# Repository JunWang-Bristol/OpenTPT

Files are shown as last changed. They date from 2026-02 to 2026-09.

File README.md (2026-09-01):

# OpenTPT - Open Triple Pulse Test




OpenTPT is an open-source Triple Pulse Test (TPT) platform for magnetic characterization of core loss and inductance in power magnetics and power electronics applications.

**📄 Paper:** [Triple Pulse Test (TPT) for Characterizing Magnetic Components](https://research-information.bris.ac.uk/en/publications/triple-pulse-test-tpt-for-characterizing-power-loss-in-magnetic-c)

---

## 📋 Overview

The **Triple Pulse Test (TPT)** is a discontinuous excitation method for characterizing power losses and inductance in magnetic components. Unlike traditional continuous excitation methods, TPT uses a series of precisely timed pulses to achieve steady-state magnetic conditions rapidly.

### Discontinuous Procedure

| Pulse | Purpose | Description |
|---|---|---|
| **First Pulse** | Establish DC bias | No additional DC bias source needed |
| **Second Pulse(s)** | Stabilizing | Allow transients to settle |
| **Third Pulse** | Target cycle | Steady-state measurement |

<p align="center">


</p>

---

## ✨ Features

- ⚡ **Rapid Testing** – Short transition time (100–500 µs), ideal for end-of-line and 100% testing
- 🔄 **Bidirectional Current Flow** – Emulates practical B-H loop in PWM converters
- 💰 **Low Cost** – Reduced setup requirements compared to traditional methods
- 🌡️ **Constant Temperature** – Negligible heat generated during testing
- 📊 **DC Bias Capability** – Characterize saturation curves with built-in DC bias support
- 🖥️ **Web Dashboard** – Real-time visualization with Dash frontend

---

## 🔧 Hardware Setup

### Testing Circuit (Half-Bridge)

<p align="center">

</p>

### Example Equipment

| Component | Supported Models | Description |
|---|---|---|
| **Power Supply** | BK Precision 9129B | Dual-channel supply (V+ and V-) |
| **Oscilloscope** | PicoScope 2408B | Captures voltage/current waveforms |
| **Control Board** | NUCLEO-H503RB, ST2402 | Generates PWM pulses for H-bridge |
| **Current Probe** | 100 mV/A (recommended) | Measures inductor current, > 20 MHz |
| **Voltage Probes** | 10:1 passive probes | Input/output voltage measurement |

> 💡 **Use Your Existing Equipment!**
>
> TPT is designed to work with lab equipment you likely already have. The modular architecture uses a **`hardware_configuration.json`** file to specify your power supply, oscilloscope, and control board. Simply configure the JSON with your device names and COM ports—no need to purchase specific models listed above.
>
> Adding support for new hardware is straightforward: implement the interfaces in `power_supply.py`, `oscilloscope.py`, or `board.py`.

---

## 🚀 Quick Start

### Prerequisites

- Python 3.8 or higher
- Hardware setup (power supply, oscilloscope, control board) connected to your PC

### Installation

1. **Clone the repository**
   ```bash
   git clone https://github.com/JunWang-Bristol/OpenTPT.git
   cd OpenTPT
   ```

2. **Create a virtual environment** (recommended)
   ```bash
   python -m venv venv
   
   # Windows
   venv\Scripts\activate
   
   # Linux/macOS
   source venv/bin/activate
   ```

3. **Install dependencies**
   ```bash
   pip install -r requirements.txt
   ```

4. **Configure hardware** – Copy and edit the hardware configuration:
   ```bash
   cp hardware_configuration_template.json hardware_configuration.json
   ```
   
   Edit `hardware_configuration.json` with your port assignments:
   ```json
   {
       "power_supply": "BK9129B",
       "power_supply_port": "COM3",
       "oscilloscope": "PicoScope2408B",
       "oscilloscope_port": "COM5",
       "board": "NUCLEO-H503RB",
       "board_port": "COM6",
       "input_voltage_probe_scale": 10,
       "output_voltage_probe_scale": 10,
       "current_probe_scale": 0.1
   }
   ```

5. **Verify your setup** – Run tests to ensure everything is configured correctly:
   ```bash
   cd tests
   python -m pytest .
   ```
   
   Or run individual hardware tests:
   ```bash
   python board_tests.py
   python oscilloscope_tests.py
   python power_supply_tests.py
   ```

### Running Your First Measurement

#### Using Python API

```python
from src.tpt import InductanceMeasurement, CoreLossesMeasurement

# Initialize the measurement system
meas = InductanceMeasurement(
    power_supply='BK9129B',
    oscilloscope='PicoScope2408B',
    board='NUCLEO-H503RB',
    power_supply_port='COM3',
    oscilloscope_port='USB',
    board_port='COM6',
    current_probe_scale=0.1  # 100 mV/A probe
)

# Demagnetize the core before measurement
meas.demagnetize()

# Create test parameters for frequency sweep
params = meas.create_balanced_pulse_train(
    voltage=10,       # Voltage amplitude (V)
    frequency=100000, # Frequency (Hz)
    num_pulses=4      # Number of pulse pairs
)

# Run measurement...
# (See examples in documentation)

# Clean up after measurement
meas.demagnetize()
```

#### Using Web Dashboard

1. Navigate to the frontend directory:
   ```bash
   cd src/frontend
   ```

2. Run the dashboard:
   ```bash
   python frontend.py
   ```

3. Open your browser to `http://127.0.0.1:8050`

---

## 📁 Project Structure

```
OpenTPT/
├── src/
│   ├── tpt.py                 # Main measurement classes (InductanceMeasurement, CoreLossesMeasurement)
│   ├── post_processor.py      # Waveform analysis and loop extraction
│   ├── board.py               # Control board interface
│   ├── oscilloscope.py        # Oscilloscope interface
│   ├── power_supply.py        # Power supply interface
│   ├── boards/                # Board drivers
│   │   ├── NUCLEO-H503RB/     # STM32 NUCLEO board firmware
│   │   └── ST2402/            # ST2402 driver board support
│   ├── oscilloscopes/         # Oscilloscope drivers
│   │   └── PicoScope.py       # PicoScope 2408B driver
│   ├── power_supplies/        # Power supply drivers
│   │   └── BK.py              # BK Precision 9129B driver
│   └── frontend/              # Web dashboard
│       └── frontend.py        # Dash-based GUI
├── tests/                     # Unit tests
├── hardware_configuration_template.json
├── requirements.txt
└── LICENSE
```

---

## 📝 Configuration Notes

### Current Probe Scale

> ⚠️ **Important:** The `current_probe_scale` defines how to convert oscilloscope voltage readings to actual current values:
>
> `Current (A) = Oscilloscope Voltage (V) × probe_scale`

| Probe Sensitivity | Probe Scale Value |
|---|---|
| 100 mV/A | `0.1` |
| 1 V/A | `1.0` |
| 10 mV/A | `0.01` |

**Common mistake:** For a 100 mV/A probe, use `scale=0.1` (not 10). The probe outputs 100 mV when 1 A flows, so you multiply by 0.1 to get amperes.

---

## 🤝 Contributors

| Organization | Contributors |
|---|---|
| **PSMA/Würth Elektronik** | George Slama, Alfonso Martinez, Matt Wilkowski |
| **University of Bristol** | Jun Wang, Binyu Cui, Jingrong Yang |
| **University of Manchester** | Cheng Zhang |

<p align="center">

</p>

---

## 📅 Roadmap

**🚧 OpenTPT – Project Under Construction**

Expected release: **APEC 2027**

---

## 📄 License

This project is licensed under the **BSD 4-Clause License** – see the [LICENSE](LICENSE) file for details.

Copyright © 2023, University of Bristol

---

## 📚 Citation

If you use this project in your research, please cite:

```bibtex
@inproceedings{OpenTPT,
  title={Triple Pulse Test (TPT) for characterizing power loss in magnetic components in analogous to Double Pulse Test (DPT) for power electronics devices},
  author={Wang, Jun and others},
  booktitle={IEEE Proc. Annual Conference of the IEEE Industrial Electronics Society (IECON)},
  year={2020}
}
```

---

## 📧 Contact

For questions, issues, or contributions, please:
- Open an [issue](https://github.com/JunWang-Bristol/OpenTPT/issues) on GitHub
- Contact the team at jun.wang@bristol.ac.uk

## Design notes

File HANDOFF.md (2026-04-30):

# Handoff: APEC Core Loss Measurement Debug

## Current State

We are debugging core loss measurement for a T26 3C90 toroid with 10 turns on the APEC branch. The measurement script runs but returns physically impossible results (B_peak=1.8mT, P_core=0mW). Current readings are essentially zero despite current probe being clamped.

## Hardware Setup

- **Board**: ST2402 half-bridge test fixture + NUCLEO-H503RB
- **PSU**: BK9129B (COM5) — using CH1 for +V, CH2 for -V (bipolar)
- **Scope**: PicoScope2408B (USB, ignores port config)
- **Board**: NUCLEO-H503RB v0.1.0 (COM4)
- **DUT**: T26 3C90 toroid, 10 turns primary, 1 turn secondary
- **Probes**:
  - V_pri: 10:1 voltage probe on CH A (scope channel 0)
  - V_sec: 10:1 voltage probe on CH B (scope channel 1)  
  - Current: Clamp-on probe 10mA/mV (100mV/A = 0.1 V/A) on CH C (scope channel 2)
- **User claims**: Current probe is clamped on correct wire, probe powered on

## Key Findings

### 1. Current Channel is Completely Dead
- **Max current reading**: 79 µA (just noise)
- **PSU confirms current flows**: 1.36 mA at 2V DC, 2.4 mA at 5V DC
- **Conclusion**: Current probe or scope channel C is not working physically
- **Likely causes**: Dead battery in clamp probe, probe not fully closed, wrong wire, scope Ch C broken

### 2. Pulse Timing is Suspicious
- **Firmware on APEC branch**: Uses DWT cycle counter for delays, HAL/LL GPIO
- **Waveform captures show unexpected patterns**:
  - 8-pulse capture: V_pri negative for 124 µs with brief 0.1 µs positive spikes
  - Single pulse capture: Output stays high for entire 500 µs acquisition
  - This does NOT match expected 10 µs pulses
- **Possible causes**:
  - DWT timer not working correctly on H503
  - `SystemCoreClock` variable incorrect
  - GPIO pins not actually switching
  - Scope triggering on wrong event

### 3. open-tpt Branch Has Better Firmware
- **Major improvements** over APEC branch firmware:
  - Bare-metal (no HAL/LL), direct register writes
  - Pre-computed DWT cycle counts (no 64-bit math at runtime)
  - Pre-computed BSRR values (atomic pin switching, no branches)
  - Configurable deadtime via `CONF:DEAD <seconds>`
  - Default minimum period: 10 ns (vs 500 ns on APEC)
  - Overhead compensation subtracts loop overhead from delays
- **The open-tpt firmware is significantly better** and should be used

### 4. Probe Scale Convention May Be Wrong
- `hardware_configuration.json`: `current_probe_scale = 0.1`
- In `PicoScope.py` `read_data()`: `data_in_volts *= probe_scale`
- For 100mV/A probe: to get Amps from volts, need `I = V / 0.1 = V × 10`
- Code multiplies by 0.1, so displayed current is actual × 0.01
- **Fix**: `current_probe_scale` should be **10**, not 0.1
- However, this does NOT explain zero current — just wrong scaling

### 5. PSU Uses Bipolar Configuration
- `tpt.py` sets both CH1 and CH2 to same voltage
- CH1 V+ → board V+, CH1 V- → board GND
- CH2 V+ → board GND, CH2 V- → board V-
- This creates ±V supply

## Tests Performed

| Test | Result |
|---|---|
| `debug_core_loss.py` | Runs, captures waveform, current = 0, extraction fails |
| `check_current_probe.py` | Current channel reads noise only, no change with PSU on/off |
| `check_psu_current.py` | PSU shows 1.36mA at 2V → circuit is NOT open |
| `verify_pulse.py` | Single pulse stays high for 500µs (wrong!) |
| `check_psu_pulse.py` | With PSU off: V_pri = 10.3V sustained; with PSU on: same |
| `analyze_waveform2.py` | 8-pulse waveform: 124µs negative, 0.21µs positive |

## Critical Issues to Fix

### Priority 1: Flash open-tpt Firmware
- The APEC branch firmware may have timing bugs
- **open-tpt branch has bare-metal, optimized firmware**
- Need to build and flash it to Nucleo
- **Problem**: No ARM toolchain installed on this machine
- **Makefile location**: `src/boards/NUCLEO-H503RB/firmware/Makefile`
- **Makefile expects**: `arm-none-eabi-gcc` at STM32CubeIDE path or on PATH

### Priority 2: Fix Current Probe
- Even with perfect pulses, current channel shows nothing
- **Action needed**: Check current probe battery, verify clamp is fully closed, try different wire position
- Alternative: Use differential probe across TP6/TP7 (1Ω shunt) instead of clamp-on probe
- If using shunt: `current_probe_scale` should be 1.0 (1V/A) and connect to CH C

### Priority 3: Fix Probe Scale
- In `hardware_configuration.json`: change `current_probe_scale` from 0.1 to **10**
- For clamp-on probe: 100mV/A → scale factor = 10
- For shunt probe: 1V/A → scale factor = 1

### Priority 4: Verify Physical Setup
- User mentioned "TP16/TP18" but board only has TP1-TP11
- J16/J18 are DUT screw terminals (not test points)
- Voltage probe should be on J19 (BNC) for DUT voltage
- Current probe should be on wire between half-bridge and DUT
- Or use differential probe on TP6/TP7 for current

## Next Steps for Next Agent

1. **Install ARM toolchain** (if you want to rebuild firmware):
   - Option A: Download from https://developer.arm.com/downloads/-/arm-gnu-toolchain-downloads
   - Option B: Install STM32CubeIDE (includes toolchain)
   - Option C: Use `choco install gcc-arm-embedded` (may need admin)

2. **Build open-tpt firmware**:
   ```bash
   cd src/boards/NUCLEO-H503RB/firmware
   # Edit Makefile to set GCC_PATH if needed
   make
   ```

3. **Flash firmware** to Nucleo:
   - Nucleo appears as USB mass storage when plugged in
   - Copy `build/TPT_SCPI_Server.bin` to the Nucleo drive
   - Or use ST-Link Utility / STM32CubeProgrammer

4. **Fix current probe issue**:
   - Ask user to verify probe battery LED is on
   - Try clamping on different wire (high-side vs low-side vs return)
   - Verify probe is closed completely (click sound)
   - Alternative: Use BNC cable + differential probe on TP6/TP7

5. **Fix probe scale in software**:
   - Edit `hardware_configuration.json`: `"current_probe_scale": 10`

6. **Re-run measurement**:
   ```bash
   venv\Scripts\python.exe debug_core_loss.py
   ```
   - Should see non-zero current
   - Should see clean square wave on V_pri
   - Core loss extraction should succeed

## Files Modified on APEC Branch

- `src/tpt.py` — Changed trigger from CH_CURRENT to CH_VOLTAGE in `_configure_scope()`
- Added diagnostic scripts (untracked):
  - `debug_core_loss.py`
  - `check_current_probe.py`
  - `check_psu_current.py`
  - `verify_pulse.py`
  - `check_psu_pulse.py`
  - `analyze_waveform.py`
  - `analyze_waveform2.py`

## Git Status

- Branch: `APEC`
- Ahead of origin by 4 commits
- Uncommitted changes in `src/tpt.py`
- Untracked diagnostic scripts

## Important Notes

- **venv location**: `C:\Users\Alfonso\OpenTPT\venv`
- **Always use venv Python**: `venv\Scripts\python.exe`
- **PicoScope PATH fix**: `$env:Path = [System.Environment]::GetEnvironmentVariable("Path","Machine") + ";" + [System.Environment]::GetEnvironmentVariable("Path","User")`
- **PSU channels**: CH1=positive rail, CH2=negative rail (both set to same voltage)
- **Board minimum pulse**: 500 ns on APEC firmware, 10 ns on open-tpt firmware

## Reference Calculations

- T26 3C90, 10 turns: L ≈ 238 µH (ungapped)
- At 10V, 50kHz, 10µs pulse: ΔI = V·Δt/L = 10 × 10µs / 238µH ≈ **0.42 A**
- With 100mV/A probe: scope sees **42 mV** — should be easily visible
- If current is actually 6.8mA (due to high resistance): scope sees 0.68mV — still visible on ±100mV range

## Questions for User

1. Is the current probe battery LED on? If not, replace battery.
2. Are you measuring voltage at J19 (BNC) or somewhere else?
3. Is the DUT actually connected between FIX_A and FIX_B screw terminals?
4. Do you hear a click when closing the current probe clamp?
5. Are you using the latest open-tpt firmware or the older APEC firmware?

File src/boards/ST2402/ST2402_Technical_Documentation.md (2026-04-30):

# ST2402 – Triple Pulse Core Tester User Manual

**Document revision:** 3  
**Hardware basis:** current ST2402 design set (updated board files)  
**Designed by:** CoreDataX / OpenTPT project

---

## 1. Purpose

The **ST2402** is a half-bridge test board used with OpenTPT to run triple-pulse style experiments on magnetic components and related power-stage setups. It is intended for controlled lab use with an external DC supply, oscilloscope, and an ST Nucleo-H503RB controller board.

In practical terms, ST2402 provides:

- A power half-bridge stage for pulse excitation.
- Isolated gate-drive paths for robust switching control.
- Dedicated connection points for DUT wiring and measurements.
- Flexible fixture/probe interfaces (BNC, headers, banana points, and test points).

---

## 2. Conceptual Design (How the Board Works)

At system level, ST2402 is organized into three conceptual blocks:

1. **Control block (Nucleo headers `J1`, `J2`)**  
   Receives timing/control from the Nucleo-H503RB and routes signals into the drive stage.

2. **Drive and power block**  
   - Two MOSFETs (`Q1`, `Q2`) form the switching half-bridge.  
   - Two isolated gate drivers (`U6`, `U8`) drive the switches.  
   - Isolated DC/DC modules (`U1`, `U7`) power the isolated driver domains.  
   - Input-side protection includes `F1` and `F2` (6.3A fast-acting fuse path).

3. **Fixture and measurement block**  
   Provides DUT interface and measurement breakout through BNC connectors (`J13`, `J19`), fixture headers (`J11`, `J12`, `J21`, `J22`), and test/probe points (`J14`, `J18`, `TP*`).

---

## 3. Connector Quick-Reference (Wiring Order + Probe Hookup)

Use this sequence for bring-up to reduce setup errors.

| Order | Connector(s) | What to connect | Why / Notes |
|---:|---|---|---|
| 1 | `J1`, `J2` | Install Nucleo-H503RB | Required control interface before running pulses |
| 2 | Nucleo USB | Connect to host PC | Powers control side and enables OpenTPT communication |
| 3 | `J9` | Connect DC supply input | Main board power input for the switching stage |
| 4 | `J15`, `J16`, `J17` and/or fixture headers `J11`/`J12`/`J21`/`J22` | Connect DUT / fixture loop | Use the connection style that matches your fixture and current level |
| 5 | `J13` (BNC) | Voltage probe channel (scope CH1 recommended) | Primary voltage measurement point on fixture interface |
| 6 | `J19` (BNC) | Current-related probe channel (scope CH2 recommended) | Measurement channel for current loop/return-related observation |
| 7 | `TP13`, `TP14`, `TP15`, `TP1`, `TP2`, `TP16`-`TP19` | Optional debug probes | Use for extra node visibility during tuning/debug |

> Recommended practice: keep one consistent scope channel mapping (for example CH1=voltage at `J13`, CH2=current-related at `J19`) across all test scripts and saved datasets.

---

## 4. Step-by-Step Setup Procedure

1. **Mechanical check**  
   Confirm board is mounted securely (holes `H1`-`H8`) and no conductive debris is present.

2. **Controller installation**  
   Fit the Nucleo-H503RB onto `J1`/`J2`; connect USB to host.

3. **Power wiring**  
   With supply output OFF, wire 12V DC input to `J9`.

4. **DUT wiring**  
   Connect the DUT loop using the selected fixture interface (`J15`/`J16`/`J17` or `J11`/`J12`/`J21`/`J22`).

5. **Instrumentation hookup**  
   - Scope CH1 to `J13` BNC.  
   - Scope CH2 to `J19` BNC.  
   - Add auxiliary probes at `TP*` only if needed.

6. **Power-up sequence**  
   Turn on control side first (USB/Nucleo), then enable DC supply output.

7. **Run test from OpenTPT**  
   Start with conservative pulse settings and increase stress gradually.

8. **Power-down sequence**  
   Disable DC supply output first, then remove/adjust DUT wiring.

---

## 5. Pre-Test Checklist

Complete this checklist before enabling pulses:

| Check | Item | Pass Criteria |
|---:|---|---|
| ☐ | Mechanical integrity | Board is firmly mounted; no loose hardware; no conductive debris |
| ☐ | Nucleo installation | Nucleo-H503RB seated correctly on `J1`/`J2`; USB link active |
| ☐ | Input wiring | DC input polarity and terminal tightness at `J9` verified |
| ☐ | DUT loop wiring | DUT connected to intended fixture points; no accidental shorts |
| ☐ | Scope channels | CH1 on `J13`, CH2 on `J19`, probe attenuation and bandwidth settings confirmed |
| ☐ | Optional debug probes | Extra probes on `TP*` do not short adjacent nodes or ground unintended nets |
| ☐ | Fuse condition | `F1` and `F2` are present and visually/electrically healthy |
| ☐ | Supply limits | Supply voltage/current limits set to conservative startup values |
| ☐ | Software readiness | OpenTPT target configuration and pulse profile reviewed before run |

> Operator sign-off suggestion: record date, board ID, DUT ID, and scope channel map in the run log before each test.

---

## 6. Safety and Good Lab Practice

- Treat the board as a live power-electronics assembly during operation.
- Never rewire DUT or probes while supply output is enabled.
- Verify fuse condition (`F1`, `F2`) before repeated high-energy tests.
- Keep wiring short and low-inductance, especially in high-current loops.
- Start at low voltage/current and ramp only after waveform validation.

---

## 7. Practical Usage Notes

- Keep measurement grounding/probe return strategy consistent between runs.
- If waveforms are noisy, improve lead routing before changing firmware settings.
- Record connector/probe mapping with each dataset to maintain traceability.
- Use the same fixture connector set for a full campaign to avoid wiring drift.

---

## 8. Hardware Reference Summary

### 8.1 Main power/control devices

| Ref | Device |
|-----|---|
| `Q1`, `Q2` | STB100N10F7 |
| `U6`, `U8` | Si8271DB |
| `U1`, `U7` | R1S-1212 |
| `U2` | LM317L_SOT-89 |
| `F1`, `F2` | 6.3A fast-acting fuse path |

### 8.2 Board construction

- 2-layer PCB (`F.Cu`, `B.Cu`)
- 1.6 mm board thickness
- 8 mounting holes (`H1`-`H8`, M3 class)

---

## 9. Manufacturing Outputs

Manufacturing data is available in:

- `r1 Gerbers/`
- `r2 Gerbers/`
- `r3 Gerbers/`

Use the latest validated set in your release process.

---

*Last updated: 2026-02-17 (manual-style update for revised ST2402 board files)*

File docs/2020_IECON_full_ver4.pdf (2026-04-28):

# Triple Pulse Test (TPT) for Characterizing Power Loss in Magnetic Components in Analogous to Double Pulse Test (DPT) for Power Electronics Devices

Jun Wang, Xibo Yuan, Navid Rasekh Department of Electrical and Electronic Engineering, University of Bristol Bristol, United Kingdom
Email: jun.wang@bristol.ac.uk; xibo.yuan@bristol.ac.uk; navid.rasekh@bristol.ac.uk

Abstract—Power loss modelling of magnetic components becomes increasingly important in the design of modern power electronic converters, especially in the case of higher switching frequencies enabled by emerging wide-bandgap devices. While the modelling of the active power electronic devices is relatively mature and straightforward, the estimation of the passive magnetic component loss remains challenging, including both the core loss and winding (copper) loss. As indicated by recent studies, the accurate prediction of the core loss in power converters relies on rectangular-voltage-excited measurements. To characterize the core loss with high-frequency rectangular excitations and dcbiases, a Triple Pulse Test (TPT) has been proposed and is further extended in this paper. The TPT involves a discontinuous procedure and a bidirectional, half-bridge excitation circuit that supplies transitional high rectangular voltage and high current. The importance and practical considerations of achieving closed dynamic BH loops are discussed. The proposed TPT is analogous to the common Double Pulse Test (DPT) for power electronics devices in terms of the testing circuit, the measurement instruments, and the discontinuous procedure. Moreover, the winding loss characterization can also be achieved by the TPT, given the winding loss can be very difficult to predict especially for randomly wound components where analytical equations cannot be applied accurately. Eventually, a complete loss dataset for one magnetic component design (i.e. same core material, shape and winding arrangement) can be built from TPT, which can be utilized to accurately model the inductor loss in power converter applications.

Keywords—triple pulse test, double pulse test, core loss, BH loop measurement, copper loss

I. INTRODUCTION
Along with the development of high-switching-frequency power converters, the loss modelling of the active and passive components become increasingly important in order to achieve reliable thermal design and reduce the prototyping cycles. The modelling and characterization of the power electronics devices, such as IGBTs and MOSFETs, are relatively mature and accurate, which includes the conduction loss and the switching loss. In practice, the conduction loss and switching loss of power devices are characterized experimentally by the manufacturers, for which the results are widely supplied to the users in the manufactuerer datasheets. While the conduction loss can be simply modeled as an on-state resistance, e.g. Rds(ON) for MOSFETs, the switching loss is commonly modeled in the form of the loss energy of one switching transition in relation to the switching voltage and current, which is characterized through the Double Pulse Test (DPT) [1] against various configurations and operating points. The tested dataset enables the users to estimate the switching loss for real operating conditions (switching voltage and current) without reproducing the detailed transitional voltage and current waveforms.
The loss modelling of magnetic components is more challenging, in which the core loss is the major challenge. Because of the non-linear nature, the core loss cannot be modelled fully by physical models. The only practical approach to estimate the core loss is based on empirically measured dataset [2], [3], which in principle is similar to the switching loss dataset for power electronics devices. Given the pre-produced core loss data, the instantaneous magnetization and demagnetization process of the magnetic cores do not need to be modelled to predict the power loss occurred. Currently, the common practice of the manufacturers is to provide a core loss datasheet for one particular type of magnetic material, which is measured from sinusoidal excitations. As the widely accepted approach, the provided datasheet is then converted to Steinmetz Equation (SE) parameters as follows for the loss prediction purpose in sinusoidal-excited applications, e.g. electric machines

P = kf

∆B

| (1)
However, for power electronics applications with rectangular excitations, the core loss prediction is less straightforward. Academia and industry have not reached a consensus on a generally applicable approach in this case. The conventional approaches based on Steinmetz Equations and its variations, e.g. improved generalized Steinmetz equations (iGSE), cannot accurately account for the rectangular excitation with dc-biased current and a harmonic spectrum crossing a wide range of frequencies [2], [4]. The frequency dependency of the SE parameters [2] indicates that the SE is not a perfect curve-fitting expression for the non-linear core loss phenomenon.
As a recent advance, academics have proposed to collect the core loss data directly from rectangular excitations for better accuracy of estimation [4]–[7]. The rectangular-excitationbased dataset can be straightforwardly utilized in predicting the core loss of filter inductors in pulse width modulated (PWM)

converters as presented in [6]–[9]. Implementing rectangular excitation voltage to build the core loss dataset can be seen as emulating the actual waveforms, that an inductor will experience in a power converter, in a standalone test setup.
In terms of the winding loss of magnetic components, although it can be well predicted by analytical models or finite element analysis (FEA), it still poses challenges in practice where the physical positioning of the wires cannot be accurately modelled, e.g. in a hand-wound inductor with random conductor placement. With the increase of frequency, the proximity effect and skin effect can also be very challenging to model accurately. Therefore, the practical solution could also be to generate a copper loss dataset from empirical testing.
At the time of this work, the manufacturers still do not provide the inductor loss data measured from rectangular excitations. Moreover, the available manufacturer datasheets of core loss are typically for per magnetic material only, rather than per inductor/transformer. In contrast, each power electronics device, e.g. one packaged IGBT or MOSFET, commonly has its individual switching loss data in the datasheet, instead of just the properties of the semiconductor material. As demonstrated in [7], if the core loss data is generated for each inductor/transformer design (i.e. same core material, shape and winding arrangement), it will be more accurate and more user-friendly for power electronics applications. If the empirical testing is performed on one inductor/transformer design, the copper loss can also be included as the windings are fixed. To test one built inductor/transformer design, it may require a high-voltage/current excitation circuit and high-power measurement instruments, while testing one magnetic material normally requires only a low-power test setup.
This paper proposes and demonstrates a triple pulse test (TPT) that involves a discontinuous testing procedure and a high-voltage/current, rectangular excitation circuit. Due to the discontinuous feature, the TPT procedure simplifies the testing process and requires only a transient power capability of the test setup. While the TPT concept has been brought up in a previous publication [7], this work demonstrates supplementary practical considerations of the testing and, more importantly, further extends its concept to include the copper loss to form a complete loss dataset of a magnetic component. Additionally, a detailed comparison between the Triple Pulse Test and the Double Pulse Test is demonstrated in this work to show their resemblance in terms of concept and practicability for better understanding by the audiences, e.g. power electronics engineers. An experimental case study is then conducted on one built inductor in a test rig.

II. TRIPLE PULSE TEST FOR CORE LOSS UNDER RECTANGULAR EXCITATION VOLTAGE
A. Two-winding dynamic B-H loop measurement
To measure the loss of magnetic components, there are mainly two practical approaches: (1) thermal-based approach such as calorimetric method and graphic method [10] (2) electrical-based approach, i.e. the two-winding method. The two-winding dynamic B-H loop measurement has been widely applied in characterizing the high-frequency core loss of a magnetic component/material [6], [11]. Compared to the thermal based method, the two-winding method has the following benefits:
- Include only the core loss, i.e. the hysteresis loss, eddy current loss and residual loss, and exclude the copper loss. By using the secondary sensing winding, the voltage drops owing to the resistance of the primary winding and leakage inductance are not included in the measurement [11].
- Ability to capture the core loss in a very short transition, e.g. a switching cycle of in high-frequency power converters, without the need to achieve thermal steady state. The transitional core loss is captured in the form of a dynamic B-H loop [6].
Fig. 1 shows a top-level illustration of the B-H loop measurement, which is formed by a power converter, the magnetic device for testing and the measurement instruments.

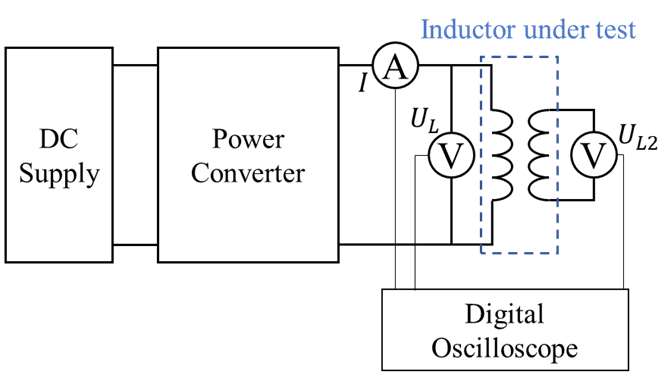
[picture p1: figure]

Fig. 1. B-H loop measurement setup.

The magnetic-domain operation of the magnetic core is found in the form of the trajectory in the plane of flux density B and the magnetic field H. The B and H are captured from the electrically measured waveforms, i.e. the excitation current I and the open-circuit voltage on a sensing coil UL2, as expressed in (2) and (3).

H(t) =

N

- I(t)
l

(2)

B(t) =

1
NA

U(t) dt

(B(0) = 0) | (3)

where N1 is the number of turns of the main winding of the inductor; N2 is the number of turns of the flux-sensing winding; Ae is the effective cross-section area of the core; le is the effective length of magnetic path of the core.
When the BH trajectory forms a closed loop over a period of 2T, the core loss occurred in this process is expressed as

E = A

l H dB =

N
N

I(t) ∙ U(t) dt

| (4)

Note that the measured dynamic BH trajectory should ideally form a closed loop. If the measured BH loop is unclosed, it indicates that the magnetization/demagnetization process is not fully completed, which results in reactive energy unreturned from the core that will be incorrectly accounted as the loss in (4). This case is also elaborated in [6], where an open-looped trajectory leads to excessive loss incorrectly included for a high-frequency dynamic loop.
Additionally, the existing core loss calculation methods for PWM converters relies on an important assumption – the magnetization (positive) cycle and the demagnetization (negative) cycle equally consumes half of the total loss in the whole loop. This assumption enables the PWM waveforms to be decomposed into pulse segments for the core loss calculation as implemented in [4], [7], [8]. This assumption only stands in the case of a closed and symmetric BH loop.
B. Excitation circuit
This section discusses the excitation circuit for the rectangular-excited BH loop measurement. As introduced, to form a dataset that can be later used for estimating the core loss in power converters, it is intended to emulate the same operations of the core in a standalone BH loop measurement. To accurately emulate the operations in a PWM converter, the typical inductor waveform shown in Fig. 2 must be considered.

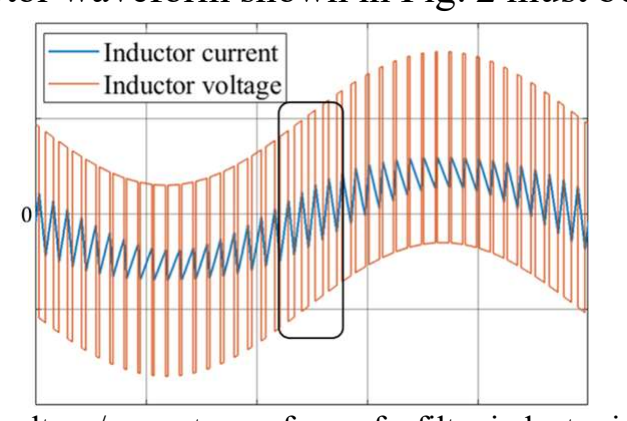
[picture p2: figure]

Fig. 2. Typical voltage/current waveform of a filter inductor in a two-level dc/ac PWM converter.
As shown in the figure, on switching cycle basis, the inductor experiences quasi-rectangular excitations with various amplitudes, duty cycles and dc-biased current. If the deviceunder-test is a high-power inductor, the excitation circuit needs to have the ability to emulate the high voltage and high current as in a real high-power converter application.
Note in some switching cycles marked in Fig. 2, the current is bidirectional, which passes through the positive and negative region. This case happens when the dc-bias current is small while the current ripple amplitude is large. Therefore, ideally, the excitation circuit for the BH loop measurement should be bidirectional to account for these switching cycles with bidirectional current flows.
In previous studies [6], [8], a dc chopper (buck) circuit has been utilized as the excitation circuit for the BH loop measurement, which is the simplest solution for testing dc-biased operating points. However, this excitation circuit is unidirectional and cannot cover the operating points with bidirectional current flows. If these cases are not evaluated, the subsequent core loss dataset would be incomplete for the estimation purpose.
There are two solutions to achieve the target high-voltage/current bidirectional excitation. Firstly, as the most common solution of a single-phase dc/ac converter, a full bridge can be used for the testing as implemented in [12], [13]. However, the most significant flaw of this configuration is the significant device voltage drops causing the asymmetric rectangular voltage on the inductor under a high dc-bias current, as pointed out in [7]. An asymmetric rectangular voltage will lead to unclosed BH loops as a result of unequal volt-second product applied on the inductor in the positive cycle and the negative cycle respectively.
To overcome this limitation, a half-bridge excitation circuit with two dc sources is proposed by us in [7], which is presented in Fig. 3. Although this half-bridge configuration has been implemented ealier in [14], it did not have two dc courses in series. Fig. 3 shows the case where the target dynamic BH loop is “floating” in the first quadrant of the BH plane due to the dc-biased current, which is the major case in the intended testing. In this case, the inductor current is always positive so that only switch T1 needs to operate.

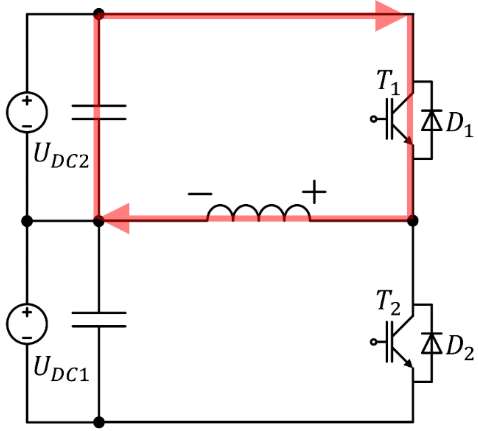
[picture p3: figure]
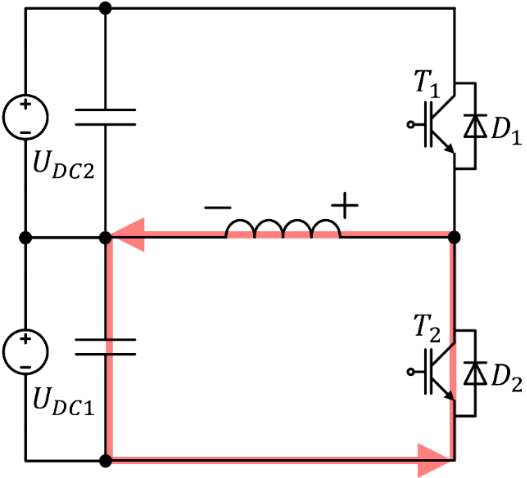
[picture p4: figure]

(a) positive cycle | (b) negative cycle
Fig. 3. Proposed half-bridge test circuit with dc-biased current
The inductor voltage in the positive cycle and the negative cycle in this circuit is expressed as follows considering the device voltage drops
U = U − U | (5)
U = −(U + U) | (6)
Under a high dc-biased current, if the two dc capacitor voltages are equal and not adjustable, there will be a difference between UL+ and |UL −|. Note this asymmetric is caused not only by unequal UDiode and UIGBT, but also the plus/minus sign in (5) and (6). For example, if UDC2= UDC1 = 50V, UIGBT = 3 V and UDiode = 2 V, the inductor-under-test will experience a rectangular voltage with +47V in the positive cycle and -52 V in the negative cycle. By adjusting the two separate dc source voltages (UDC2 and UDC1), it can compensate the asymmetric rectangular voltage amplitudes due to the device voltage drops under a dc-biased current. This degree of freedom does not exist in the full-bridge configuration or the regular half-bridge configuration. Note when the target current is bidirectional, both T1 and T4 need to operate and the asymmetric of voltage amplitude will not be a concern due to the complementary conduction path.
C. Triple pulse test procedure
Based on the proposed testing circuit, a TPT procedure is proposed as follows with the testing waveforms illustrated in Fig. 4. The amplitude of the testing is fixed to half the dc-link voltage. To build up a dc-bias current, an initial wide gate pulse is applied to turn on T1, which is referred as the 1st pulse. Next, as the second stage, narrower pulses with the target width (T= t2 = t2+ = t2−) are applied, which is referred as the 2nd pulse or pulses. These cycles intend to drive the inductor into an electrical/magnetic steady state operating at the target high-frequency dynamic loop. Once the waveforms are stabilized, it enters the third stage, where one target full cycle of the dynamic loop is captured. This captured cycle should form a closed BH loop that features a certain dc-biased current (premagnetization), volt-second product (flux density swing) and voltage amplitude (dB/dt). After the third stage, T1 is turned off and the current freewheels in the diode D2 to release the energy stored in the inductor until it is fully discharged. The whole process last for a period of typically 100 ~ 500 μs. This discontinuous concept and testing waveform are similar to the approach used in the saturation property test in [15].

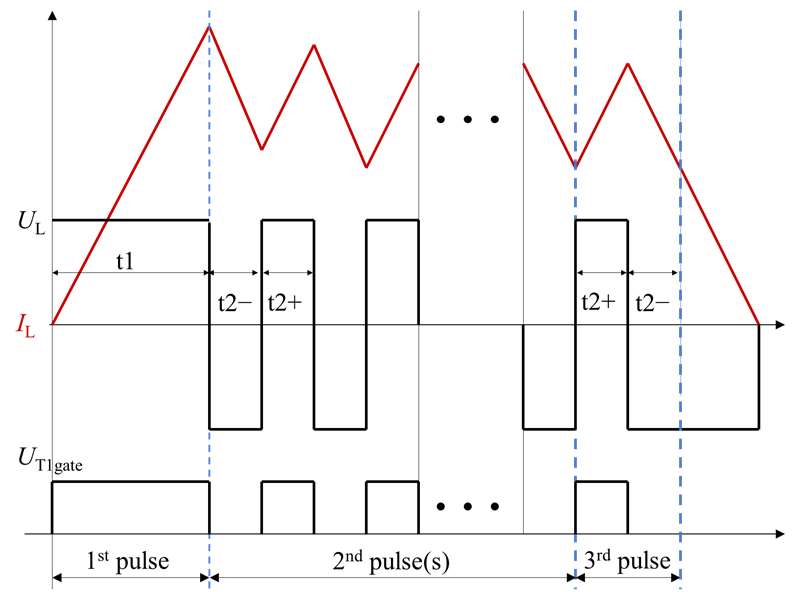
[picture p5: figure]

Fig. 4. Illustration of the testing waveforms of the TPT with a dc-bias current
The width of the first pulse t1 is calculated from the target dc-bias current, the voltage amplitude and the inductance of the component (which is assumed to be the nominal value) as

t = I

- L/U + 0.5 ∙ t

(7)

This TPT procedure is discontinuous as it intends to capture the first steady-state dynamic BH loop and avoid unnecessary further operations. If the excitation were continued, the BH trajectory would only repeat the target dynamic loop because it already reached the steady state. Therefore, the proposed TPT procedure should lead to the same results as regular approaches where the excitation is continuous. This discontinuous capturing technique is implemented through the digital oscilloscope and post-processing software such as Matlab. To reduce the effect of random noise, the same procedure can be repeated, and the averaged trajectory of the target BH loop can be obtained from repeated runs, e.g. 20 runs. The proposed discontinuous procedure has the following merits:
a) The testing setup does not require the full continuous power capacity. The transitional high dc-biased current (e.g. >100A) is drawn from the dc-link capacitors rather than the dc power supplies, which will not trigger the current protection of the dc sources. In the case of measuring the current with a current probe, this procedure avoids a large dc current-time product that is limited by the design of the current probes.
b) Because of the short testing transition, very small amount of heat will be generated, which can be neglected. Therefore, this testing does not vary the temperature of the componentunder-test. Additionally, it does not need a full-scale cooling heatsink to process the heat generated in the testing. For example, if the inductor is designed for high-power operations accompanied with a liquid cooling system, it does not require the full-scale cooling system in the discontinuous TPT setup.
D. Summary and practical considerations
A triple pulse test procedure is introduced in this section, which involves a half-bridge excitation circuit and a discontinuous procedure. Note in existing approaches, the alternative to establish the dc-bias current is to apply a separate dc current source through a third bias winding [16]. In contrast, the proposed TPT procedure does not require extra hardware while the dc-biased current is established through adjusting the width of the first pulse.
As discussed, forming a closed dynamic BH loop is important to achieve an accurate capturing of the core loss over a target cycle. An unclosed dynamic BH loop leads to incorrectly captured core loss that does not belong to the target dynamic cycle, which compromises the critical assumption that the magnetizing and demagnetizing cycles each consumes half of the core loss of the loop. In practical TPT, there are following aspects that need to be considered to achieve a closed BH loop:
- The rectangular excitation voltage in the positive and negative cycles should be symmetric which features:
o Equal voltage amplitudes
o Equal volt-second product
- The operation of inductor core should enter the steady state
- The phase discrepancy and dc offset of the probes should be compensated
To achieve the symmetric rectangular excitation should be ensured, the presented half-bridge excitation circuit provides the ability to compensate the unequal amplitudes due to device voltage drops by adjusting the two dc-link capacitor voltages, as demonstrated in Section II.B. Apart from the equal voltage amplitudes, the pulse widths of the positive/negative cycles also need to be calibrated to prevent unequal volt-second product and subsequently to avoid unclosed B-H loop. If the power devices in the excitation circuit are IGBTs, the turn-on and turn-off transitions last unequal duration. For example, for power module SKiM301TMLI12E4B, the turn-on time is 218 ns and the turn-off time is 355 ns due to the tail current. This unequal switching time will lead to unequal volt-second product on the inductor in the positive and negative cycles, which will result in unclosed BH loop in the testing. This non-ideal operation can be compensated in the generation of gate signals through a fine adjustment of the pulse widths. For example, considering a longer turn-off transition of IGBTs, the width of the positive cycle t2+ should be reduced in practice.
Apart from the symmetricity of the excitation voltage, the operation of the inductor core should enter the steady state to achieve a closed target BH loop, as intended in the TPT concept. This objective can be realized by adjusting the number of stabilizing pulses on case to case basis.
From the measurement point of view, the phase discrepancy between the voltage and current probes in the testing will significantly affect the accuracy of the core loss measurement

[3]. The reason is that the pair of voltage and current used to obtain the core loss energy in (4) has a phase difference of close to 90°, because the operation of the inductor/transformer is mainly reactive. The error in the phase discrepancy will incorrectly count the energy absorbed and returned from the reactive cores, and lead to incorrect consumed loss captured in (4). To address this issue, the phase discrepancy needs to be carefully calibrated, e.g. through a de-skew tool and the de-skew function on the oscilloscope. Alternatively, the reactive voltage cancellation concepts [17], [18] have been proposed in recent years which add an additional resonance capacitor or reference transformer in the testing circuit, so that the voltage/current pair under integration in (4) will be in phase. In short, the phase discrepancy issue lies in the measurement and load circuit of the testing. The excitation circuit and the procedure in the proposed TPT is still applicable in the reactive voltage cancellation circuits.
In practice, even though the above measures are all implemented, the target B-H loop may still not completely close due to uncontrollable non-ideal factors in the test rig (e.g. ringing in the voltage due to circuit parasitics). In this case, the BH loop can be virtually closed by connecting the start and end point in the data post-processing to minimize the effect of unreturned reactive energy shown as unclosed BH loop.

III. ANALOGY BETWEEN DPT AND TPT
For better understanding by the audiences, this section elaborates the resemblance between DPT and TPT from the following aspects in terms of both concept and practical implementation:
- High-voltage/current testing circuit and instruments
- Discontinuous concept with the first pulse to build up the dc-bias current
- Format of the generated dataset
Firstly, the testing circuits of both TPT and DPT are based on a half-bridge topology. Illustrations of both testing circuits are shown in Fig. 5. The power devices are in the same configuration in both circuits, which can be a half-bridge power module for instance. When the inductor is tested with a dc-bias current, only switch T1 is controlled by the triple gate pulses as shown in Fig. 5(a), which is similar to the DPT in Fig. 5(b) where the IGBT/MOSFET under test is fed with double gate pulses. Both testing circuits desire a large dc-link capacitance, because ideally the dc-link voltage needs to stay relatively constant (e.g. the voltage deviation stays below 1%) over the whole testing window while the transitional current/energy in is drawn from these capacitors. The main difference in the TPT is the two dc sources required for the voltage drop compensation purpose. In terms of the testing instruments, both setups require high-bandwidth current and voltage probes to capture the detailed transitional voltage/current waveforms. In both cases, the waveforms are captured in digital oscilloscopes and postprocessed by computer software, such as Matlab.
Secondly, both testing procedures share the discontinuous concept. The typical testing waveforms are illustrated in Fig. 6.

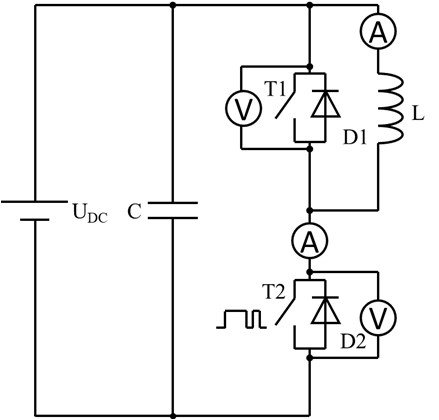
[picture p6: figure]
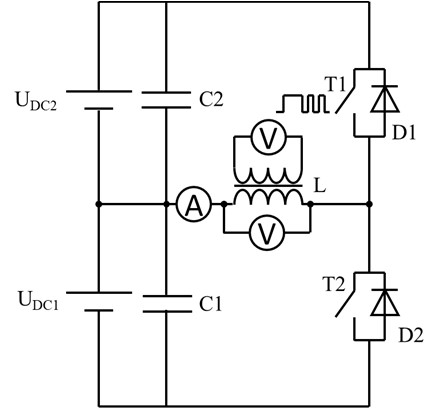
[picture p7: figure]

The discontinuous procedure reaches the target window of interest with minimized process and avoids unnecessary operation. As discussed in Section II.A, the discontinuous concept is beneficial mainly because it reduces the power requirement of the testing setup and avoids temperature variation due to the little heat generated in the short transition. The typical window of the captured waveform of DPT is at the level of 100 ns, which focuses on the turn-on/turn-off edges. For the TPT, the captured window of a TPT is typically at 10 ~ 200 µs for example, which covers one full cycle of the rectangular excitation, e.g. 5 kHz ~ 100 kHz. Additionally, both testing procedures utilize the first pulse to establish a dc-bias current. The purpose of it is to emulate the switching current of the power device in the DPT and to emulate the dc-biased premagnetization of the magnetic core in the TPT.

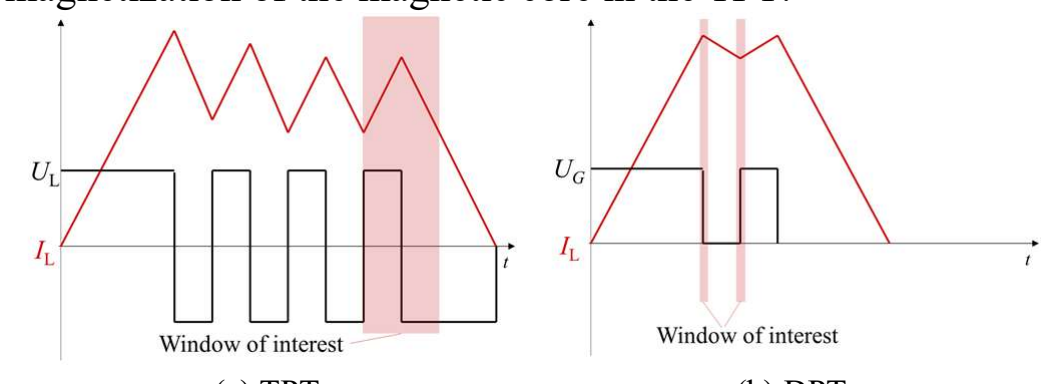
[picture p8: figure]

(a) TPT | (b) DPT
Fig. 6. Illustration of typical testing waveforms (inductor current IL; inductor voltage UL; device gate voltage UG)
Thirdly, in terms of the outcome of the testing, TPT and DPT also lead to similar form of the generated dataset. DPT results in the loss energy of one switching transition that is described by three variables as following, regardless of the temperature
E(mJ) = f(R,U,I) | (8)

where Usw is the switching voltage, Isw is the switching current and RG is the gate resistance.
For the magnetic components, the core loss under rectangular excitation is also expressed in a three-dimensional dataset as follows regardless of the temperature [6]

E(mJ) = g(∆B,

dB
dt , H) | (9)

where Ecore is the core loss energy of one closed BH loop; ΔB is the flux density swing; dB/dt is the change rate of the flux density and H0 is the dc-bias of the magnetic field.
When it comes to one inductor design, due to the fixed core geometries, the three variables above can be converted to the
(a) (b)
Fig. 5. Illustration of testing circuit (a) TPT for inductor core loss with dc-bias (b) DPT for switching loss of T2/D1 primary-side electrical variables to form the “user-friendly core loss map” [7] as

E(mJ) = ℎ(U

- T,U
,I) | (10)

where Ecore is the core loss energy of one pulse; UL is the main inductor winding voltage amplitude measured in Fig. 1, T is the period of one pulse (half of a symmetric BH loop), I0 is the biased current.
In short, regarding the form of the empirically generated dataset, the switching loss data from DPT and the core loss data from TPT are both defined by three operational variables.

IV. TPT FOR COPPER LOSS AND TOTAL INDUCTOR LOSS
A. Measurement of copper loss and total inductor loss in TPT The presented TPT is able to account for not only the core loss, but also the copper loss. By replacing the secondary voltage UL2 in (4) with the main winding voltage UL in Fig. 1 as below, the total inductor loss can be obtained for one BH loop segment, which is also brought up in [17], [18]
Q = I(t) ∙ U(t) dt

| (11)

The difference between the measured total inductor loss and the core loss is the copper loss. Fig. 7 shows an experimental example of the integration of the instantaneous power over the primary/second voltage and the current in a target cycle. Over one full cycle, the end point of the red trajectory indicates the total inductor loss occurred in this cycle, which is 1.397 mJ in this case, while the blue trajectory indicates the core loss, which is 1.174 mJ in this case. Therefore, the difference in between these two loss values is the copper loss, which is 0.223 mJ in this case. This example demonstrates that both the copper loss and core loss can be captured in the TPT for one cycle of rectangular excitation.

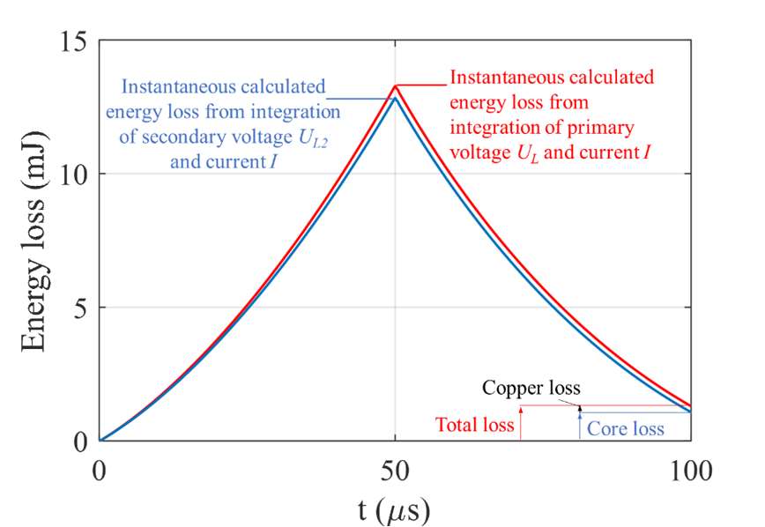
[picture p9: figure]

Fig. 7. Integration of instantaneous power over a target cycle captured in experiment (corresponds to the target cycle in Fig. 10 in Section V)

B. User-friendly total loss dataset for one inductor design Because the total inductor loss can be captured in the TPT, this work proposes that a user-friendly total loss dataset should be produced to the users for each inductor design based on empirical measurements through TPT. Ideally, the inductor/transformer loss dataset should be measured by the manufacturers, so that the users can utilize these data directly in modeling the power loss of magnetic components in power electronics. This is a similar concept as the switching loss datasheet supplied by the manufacturers of IGBTs/MOSFETs. As introduced, one operating cycle of an inductor core can be described by three variables: UL·T, UL and I0. The copper loss dataset can also be expressed by the same three variables. With reference to the conventional copper loss models, the variable I0 reflects the dc copper loss. The other two variables, UL ·T and UL represent a unique rectangular excitation pattern and a unique triangular current waveform in an inductor, which reflects the ac copper loss.
In short, the copper loss and the total loss of an inductor/transformer design can also be expressed by the three variables in a user-friendly loss map, i.e. UL ·T, UL and I0. Once this three-dimensional loss dataset is provided by the manufacturer, the users can model the inductor loss by modelling the ideal inductor voltage/current waveforms. In this way, the prediction of the dynamic non-ideal effects is avoided, e.g. the distorted curvy shape of the inductor current [6], [7] caused by the non-linear core magnetization process.
For practical purposes, the proposed inductor loss map is implemented as a multi-dimensional lookup table as illustrated in Fig. 8, where the core loss, copper loss and total loss can be found through the three indexing variables.

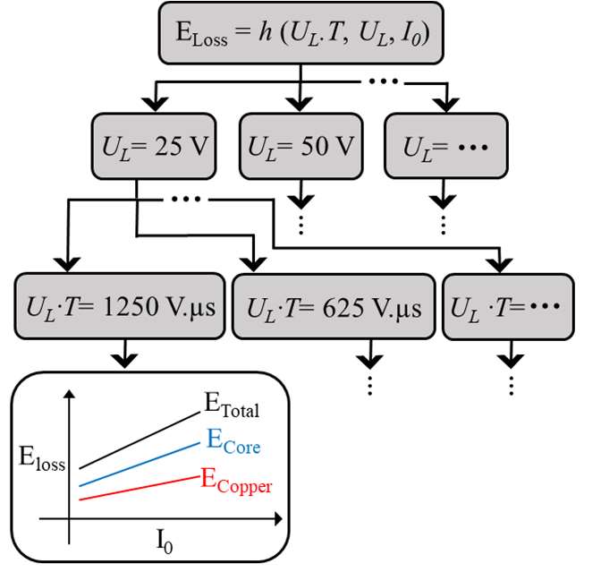
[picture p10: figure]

Fig. 8. Illustration of the proposed multi-dimensional inductor loss map

V. EXPERIMENTAL RESULTS
An experimental test rig has been built to perform the proposed TPT. A picture of the test rig is shown in Fig. 9. The components and instruments in the test rig are listed in Table I.

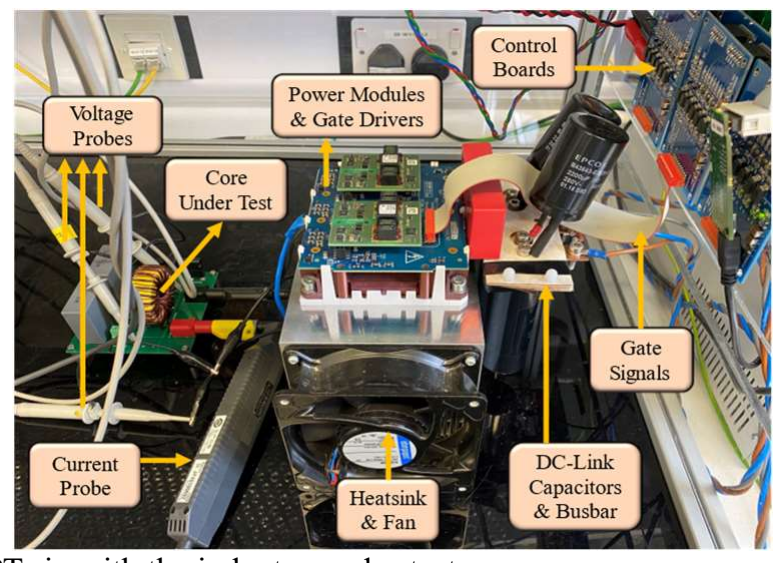
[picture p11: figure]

Fig. 9. TPT rig with the inductor-under-test

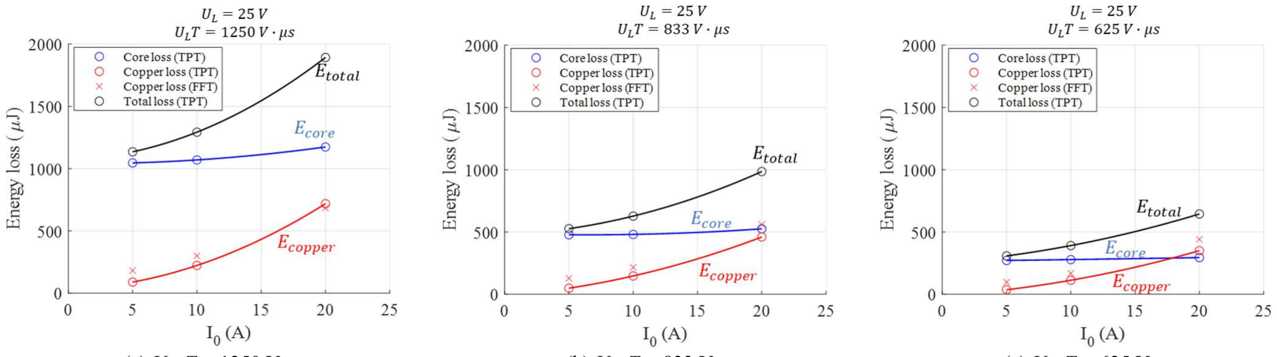
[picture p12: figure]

TABLE I COMPONENTS AND INSTRUMENTS IN THE TEST RIG
Power supplies | Elektro-Automatik TS 8000 T
Voltage probe | Keysight N2862B (150 MHz)
Current probe | Keysight N2783B (100 MHz)
Power module | Semikron SKiM301TMLI12E4B
Tested inductor | 92 µH, T184-26 from Micrometals©, N1:N2 = 24:24
Digital oscilloscope | MSO-X 3054A (500 MHz, 4 GSa/s)
Fig. 10 shows an example of the test waveform of one operating point of the inductor-under-test.

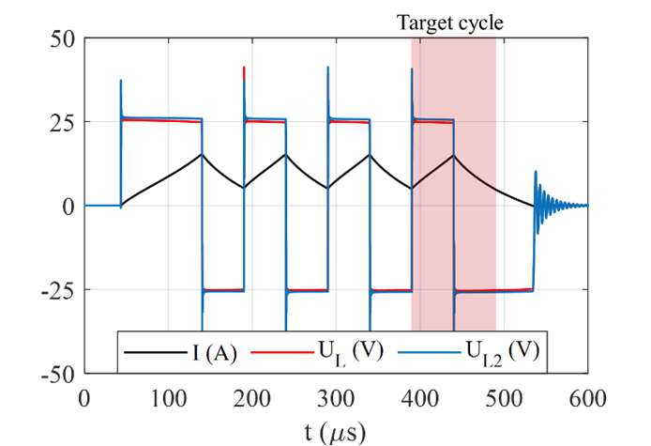
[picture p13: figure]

Fig. 10. Experimental current/voltage waveform of one TPT test (UL = 25 V, I0 = 10 A, T = 50 µs)
In this tested point, a dc-bias current is established in the first pulse, which is followed by two pulse cycles to stabilize. The target cycle is achieved in the final pulse cycle with a dc biased current of 10 A and an equivalent 10 kHz square-wave excitation voltage with 25 V amplitude.
Converted from the measured waveforms in Fig. 10, the BH trajectory of the whole TPT process is plotted in Fig. 11. It can be seen that a closed BH loop is achieved in the target cycle after two stabilizing cycles. The core loss measured in this closed BH loop is 1.174 mJ.

Fig. 11. Experimental BH trajectory of one TPT test run. ΔB = 280 mT (ULT = 1250 V·µs); dB/dt = 5600 T/s (UL = 25 V); H0 = 2200 A/m (I0 = 10 A).

By repeating the TPT for various operating point, Fig. 12 shows the inductor loss maps generated from experimental testing, which shows the copper loss, core loss and total inductor loss. The discrete results are fitted with a second order approximation. These loss graphs are expected to be included in future manufacturer datasheets as illustrated in Fig. 8. These empirical loss maps can then be utilized to accurately model the inductor loss for PWM converters once the inductor operating space (described by UL ·T, UL and I0) are identified on switching cycle basis, e.g. through analytical models presented in [9] or through simulation and experiments.
To validate the copper loss measured from TPT, the copper loss is also estimated by performing Fast Fourier Transformation (FFT) and calculating the copper loss [19] as

Pw = RwdcI

2 + RwacnIn
2

∞

n=1

(12)

where the dc winding resistance Rwdc and the ac winding resistance Rwacn across the frequency spectrum are measured by impedance analyzer Wayne Kerr 6500B; The dc current component Idc and the ac current component In across the frequency spectrum are extracted from the measured current of the target segment through FFT. The copper loss results estimated by FFT are shown in Fig. 12 as red cross markers, which show consistency with the TPT measured results. Given that the accuracy of TPT in capturing the core loss has been verified in [7], the above results validate the proposed approach in capturing the copper loss and total inductor loss through TPT.

VI. CONCLUSION
This work has proposed and elaborated a Triple Pulse Test (TPT) for characterizing the magnetic component losses. The TPT intends to emulate the operation of an inductor/transformer in a standalone test setup, where the core loss is captured in the form of the energy loss of a dynamic BH loop. The TPT involves a high-voltage/current bidirectional excitation circuit and a discontinuous testing procedure. Because the discontinuous procedure only involves several short pulses, the need of a continuous high-power test setup is avoided. To accurately extract the core loss in practice, the realized dynamic BH loops should ideally form closed loops. Practical efforts to achieve the closed BH loops are elaborated in this work,
including the compensation of unequal voltage amplitudes due ⁰ | 1000 | 2000 | 3000 | 4000 H - A/m

0

0.1

0.2

0.3

0.4

0.5

## 0.6 B ⁻ T

Premagnetization Stablizing cycles

Target cycle Demagnetization

(a) UL ·T = 1250 V·µs | (b) UL ·T = 833 V·µs | (c) UL ·T = 625 V·µs
Fig. 12. Inductor loss maps generated from experimental triple pulse tests (UL = 25V)

to device voltage drops and the compensation of asymmetric rising/falling edge due to the unequal device turn-on/turn-off time.
The concept of the proposed TPT is analogous to the wellknown Double Pulse Test (DPT) for power electronics devices (e.g. IGBTs and MOSFETs), in terms of the testing circuit, the measurement instrument, the discontinuous procedure and the format of generated power loss dataset. The similarity between the DPT and TPT is helpful for the power electronics engineers/researchers to comprehend and implement in practice.
This work also extends the TPT to include the copper loss so that the total inductor loss is characterized in the procedure, considering that the analytical modelling of copper loss can also be challenging in practice due to complex positioning of the windings and high-frequency effects. With fixed winding and core shapes, the TPT can be performed on one inductor design to build an empirical data pool of the inductor losses indexed by three variables. Considering that there are more and more standardized inductors manufactured nowadays, it can be anticipated that the manufacturers would produce the proposed inductor loss map for each inductor design. This pre-produced dataset will enable the users to accurately calculate the magnetic component loss on switching cycle basis in a power converter, without modelling the non-ideal winding positioning or the non-linear magnetization process that cannot be fully expressed by physical models.

ACKNOWLEDGMENT
The authors would like to thank the UK Royal Academy of Engineering for funding part of this work.

REFERENCES
[1] Semikron, “Determining Switching Losses of SEMIKRON IGBT Modules,” 2014. [Online]. Available: https://www.semikron.com/dl/service-support/downloads/download/semikron-application-noteswitchinglosses-en-2014-08-19-rev-00/.
[2] K. Venkatachalam, C. R. Sullivan, T. Abdallah, and H. Tacca, “Accurate prediction of ferrite core loss with nonsimisoidal waveforms using only steinmetz parameters,” in Proc. IEEE Workshop on Computers in Power Electronics, 2002, pp. 36–41.
[3] F. D. Tan, J. L. Vollin, and S. M. Cuk, “A practical approach for magnetic core-loss characterization,” IEEE Transactions on Power Electronics, vol. 10, no. 2, pp. 572–578, Mar. 1995.
[4] C. R. Sullivan and J. H. Harris, “Testing core loss for rectangular waveforms,” 2010. [Online]. Available: http://www.psma.com/coreloss/pilot.pdf.
[5] E. Herbert, “Testing core loss for rectangular waveforms, phase II supplemental report,” 2012. [Online]. Available: http://www.psma.com/coreloss/supplement.pdf.
[6] T. Shimizu and S. Iyasu, “A practical iron loss calculation for AC filter inductors used in PWM inverters,” IEEE Transactions on Industrial Electronics, vol. 56, no. 7, pp. 2600–2609, 2009.
[7] J. Wang, K. J. Dagan, X. Yuan, W. Wang, and P. H. Mellor, “A practical approach for core loss estimation of a high-current gapped inductor in PWM converters with a user-friendly loss map,” IEEE Transactions on Power Electronics, vol. 34, no. 6, pp. 5697–5710, Jun. 2019.
[8] H. Matsumori, T. Shimizu, K. Takano, and H. Ishii, “Evaluation of iron loss of AC filter inductor used in three-phase PWM inverters based on an iron loss analyzer,” IEEE Transactions on Power Electronics, vol. 31, no. 4, pp. 3080–3095, 2016.
[9] J. Wang, K. J. Dagan, and X. Yuan, “An efficient analytical inductor core loss calculation method for two-level and three-level PWM converters based on a user-friendly loss map,” in IEEE Proc. Applied Power Electronics Conference and Exposition, 2019.
[10] B. Liu, W. Chen, J. Wang, and Q. Chen, “A practical inductor loss testing scheme and device with high frequency PWM excitations,” IEEE Transactions on Industrial Electronics, 2020.
[11] V. J. Thottuvelil, T. G. Wilson, and H. A. Owen, “High-frequency measurement techniques for magnetic cores,” IEEE Transactions on Power Electronics, vol. 5, no. 1, pp. 41–53, 1990.
[12] J. Mühlethaler et al., “Improved Core-Loss Calculation for Magnetic Components Employed in Power Electronic Systems,” IEEE Transactions on Power Electronics, vol. 27, no. 2, pp. 964–973, 2012.
[13] C. R. Sullivan, J. H. Harris, and E. Herbert, “Core loss predictions for general PWM waveforms from a simplified set of measured data,” in Proc. IEEE Applied Power Electronics Conference and Exposition, 2010, pp. 1048–1055.
[14] D. Y. Chen, “Comparisons of high frequency magnetic core losses under two different driving conditions: A sinusoidal voltage and a square-wave voltage,” in PESC Record - IEEE Annual Power Electronics Specialists Conference, 1978.
[15] K. Umetani, “Improvement of saturation property of iron powder core by flux homogenizing structure,” IEEJ Transactions on Electrical and Electronic Engineering, vol. 8, no. 6, pp. 640–648, 2013.
[16] L. Chang, T. M. Jahns, and R. Blissenbach, “Characterization and Modeling of Soft Magnetic Materials for Improved Estimation of PWM-Induced Iron Loss,” IEEE Transactions on Industry Applications, vol. 56, no. 1, pp. 287–300, 2020.
[17] D. Hou, M. Mu, F. C. Lee, and Q. Li, “New high-frequency core loss measurement method with partial cancellation concept,” IEEE Transactions on Power Electronics, vol. 32, no. 4, pp. 2987–2994, 2017.
[18] M. Mu, Q. Li, D. J. Gilham, F. C. Lee, and K. D. T. T. Ngo, “New core loss measurement method for high-frequency magnetic materials,” IEEE Transactions on Power Electronics, vol. 29, no. 8, pp. 4374–4381, 2014.
[19] K. K. Marian, High-Frequency Magnetic Components, 2nd ed. Chichester: WILEY, 2014.

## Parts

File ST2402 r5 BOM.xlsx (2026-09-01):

Reference | Value | Mouser | Vendor | Price /1 | Price /10 | Qty |  | Footprint | DNP
C1,C12,C15,C16,C17,C18,C19,C20,C21,C22,C23,C24 | 10uF/50V X5R | 603-CC210KKX7R9BB106 | CC210KKX7R9BB106 | 0.66 | 0.31 | 12 | 3.77 | Capacitor_SMD:C_1210_3216Metric
C5,C7,C8,C9,C25 | 100nF, 50V | 710-885012207098 | 885012207098 | 0.10 | 0.08 | 5 | 0.50 | SMD:C_0805
C4,C6,C34,C35,C26 | 10uF, 50V | 710-885012108022 | 885012108022 | 2.23 | 2.08 | 5 | 11.15 | SMD:C_0805
C27,C36,C37 | 1uF, 50V | 710-85012207103 | 885012207103 | 0.28 | 0.26 | 3 | 0.84 | SMD:C_0805
C10,C11,C13,C14 | 1000uF, 200V | 710-861141085021 | Wurth 861141085021 | 6.30 | 5.60 | 4 | 25.20 | Capacitor_THT:CP_Radial_D30.0mm_P10.00mm_SnapIn
F1,F2 | Fuse, 6.3 A, time lag | 576-37416300000 | Littelfuse | 0.70 | 0.64 | 2 | 1.40 | Fuse:Fuseholder_TR5_Littelfuse_No560_No460
 | alt__Fuse, 6.3A, fast acting | 576-37316300410 | Littelfuse 37316300410 | 1.23 | 1.15 |  | 0.00
FH1, FH2 | Fuse holder | 576-56000001319 | Littelfuse #560, 6.3A | 0.88 | 0.81 | 2 | 1.76
J1,J2 | dnp__Conn_02x19_Odd_Even | 200-SSQ11901GD | Samtec SSQ11901GD | 5.01 |  | 0 | 0.00 | Connector_PinHeader_2.54mm:PinHeader_2x19_P2.54mm_Vertical
J7,J8 | dnp__Conn_01x02 socket, gold | 200-SSQ10202GS | Samtec SSQ10202GS | 1.03 |  | 2 | 2.06 | Connector_PinHeader_2.54mm:PinHeader_1x02_P2.54mm_Vertical
J3,J4,J5,J6 | arduino header set | 485-85 | Adafruit 85 | 1.95 | 1.95 | 1 | 1.95
J3,J4 | alt__Conn_01x08 socket, gold | 200-SSQ10802GS | Samtec SSQ10802GS | 1.99 |  | 0 | 0.00 | Connector_PinHeader_2.54mm:PinHeader_1x08_P2.54mm_Vertical
J5 | alt__Conn_01x06 socket gold | 200-SSQ10602GS | Samtec SSQ10602GS | 1.72 |  | 0 | 0.00 | Connector_PinHeader_2.54mm:PinHeader_1x06_P2.54mm_Vertical
J6 | alt__Conn_01x10 socket, gold | 200-SSQ11023GS | Samtec SSQ11023GS | 2.91 |  | 0 | 0.00 | Connector_PinHeader_2.54mm:PinHeader_1x10_P2.54mm_Vertical
J9 | Screw_Terminal_01x02 | 490-TB006-508-02BE | TB006-508-02BE | 0.78 | 0.28 | 1 | 0.78 | TerminalBlock:TerminalBlock_bornier-2_P5.08mm
J11,J12 | dnp__Conn_02x02_Top_Bottom | 200-SSQ10203FD | Samtec SSQ10203FD | 1.32 |  | 2 | 2.64 | Connector_PinSocket_2.54mm:PinSocket_2x02_P2.54mm_Vertical
J21,J22 | dnp__Conn_02x03_Top_Bottom | 200-SSQ10301GD | Samtec SSQ10301GD | 1.85 |  | 2 | 3.70 | Connector_PinHeader_2.54mm:PinHeader_2x03_P2.54mm_Vertical
J13,J19 | dnp__Conn_Coaxial | 571-227661-1 | 227661-1 | 6.01 | 4.94 | 2 | 12.02 | Connector_Coaxial:BNC_Amphenol_B6252HB-NPP3G-50_Horizontal
J15 | 4mm, pcb, socket, red | 164-6219 | Deltron 571-0500 | 1.35 | 1.18 | 1 | 1.35
J16 | 4mm, pcb, socket, blu | 164-7120 | Deltron 571-0200 | 1.35 | 1.18 | 1 | 1.35
J17 | 4mm, pcb, socket, blk | 163-6218 | Deltron 571-0100 | 1.35 | 1.18 | 1 | 1.35
Q1,Q2 | STP100N10F7 | 511-STP100N10F7 | ST TO-220 | 2.86 | 1.38 | 2 | 5.72
 |  |  |  |  |  | 2 |  | heat sink
R1,R2,R3,R4,R5,R6,R7,R8 | R820, 1%, 1206, 100ppm | 71-RCWE1206R820FKEA | RCWE1206R820FKEA | 0.28 | 0.14 | 8 | 2.24 | Resistor_SMD:R_1206_2012Metric
 | alt__R820, 1%, 1206, 200ppm | 667-ERJ-8BQFR82V | ERJ-8BQFR82V
R9,R10 | 3k, 1W, axial, flameproof | 603-RSF100JB-73-3K | RSF100JB-73-3K | 0.26 | .097/.059 | 2 | 0.52 | Resistor_THT:R_Axial_DIN0309_L9.0mm_D3.2mm_P15.24mm_Horizontal
R11 | 470R | 603-RC0805FR-07470RL | RC0805FR-07470RL | 0.10 | 0.01 | 1 | 0.10 | R_0805
R12 | 1k43 | 603-RC0805FR-071K43L | RC0805FR-071K43L | 0.10 | 0.01 | 1 | 0.10 | R_0805
R13,R14,R20,R21 | 10k | 603-RC0805FR-0710KL | RC0805FR-0710KL | 0.10 | 0.01 | 4 | 0.40 | R_0805
R18,R19 | 100R | 603-RC0805FR-07100RL | RC0805FR-07100RL | 0.10 | 0.01 | 2 | 0.20 | R_0805
R22,R24 | 88R7 | 603-RC0805FR-0788R7L | RC0805FR-0788R7L | 0.10 | 0.01 | 2 | 0.20 | Resistor_SMD:R_0805_2012Metric
R23,R29 | 2R | 603-RC0805FR-072RL | RC0805FR-072RL | 0.10 | 0.01 | 2 | 0.20 | Resistor_SMD:R_0805_2012Metric
R30,R31 | 100k | 603-RC0805FR-07100KL | RC0805FR-07100KL | 0.10 | 0.01 | 2 | 0.20 | Resistor_SMD:R_0805_2012Metric
TP1,TP2 | 4mm safety socket | 510-CT4397-08-2 | CalTest CT4397-08-2 | 2.20 | 2.20 | 2 | 4.40 | many alternates, any color
TP11, TP12, TP13 | loop, blk | 534-5011 | Keystone 5011 | 0.29 | 0.23 | 3 | 0.87
TP4,TP10,TP14 | loop, wht | 534-5012 | Keystone 5012 | 0.29 | 0.23 | 3 | 0.87
TP5,TP6 | loop, org | 534-5013 | Keystone 5013 | 0.29 | 0.23 | 2 | 0.58
TP16,TP17 | threaded stud clip | 706-02-0 | Grayhill 02-0 | 5.71 | 5.19 | 2 | 11.42
 | alt__5 way binding post, red | 548-BU-P3760-6 | BU-P3760-6 | 5.16 | 4.03 |  | 0.00
 | alt__post, push type, red | 706-29-100RED | Grayhill 29-100 RED | 7.45 | 6.07 |  | 0.00
TP17, TP19 | threaded stud clip | 706-02-0 | Grayhill 02-0 | 5.71 | 5.19 | 2 | 11.42
 | alt__5 way binding post, blk | 548-BU-P3760-0 | BU-P3760-0 | 5.16 | 4.03 |  | 0.00
 | alt__post, push type, blk | 706-29-100BLK | Grayhill 29-100 BLK | 7.45 | 6.07 |  | 0.00
U1,U7 | R1S-1212 |  |  | 7.47 | 7.35 | 2 | 14.94 | Package_SO:SO-14_3.9x8.65mm_P1.27mm
U2 | LM317LCPK | 595-LM317LCPK (https://www.mouser.com/ProductDetail/595-LM317LCPK) |  | 0.44 | 0.44 | 1 | 0.44 | SOT-89
U6,U8 | Si8271DB-IS | 634-Si8271DB-IS |  | 3.56 | 2.68 | 2 | 7.12
 |  |  |  |  |  |  | 126.20

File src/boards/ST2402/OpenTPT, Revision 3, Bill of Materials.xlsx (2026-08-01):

Index | Reference | Value | Footprint | Mfg / Part Number | Replacement Part | Qty Per Assembly | Mouser SKU (ref) | DKPN | DK, Qty Price Break | Price Each | Qty x3+10%+Break | Expan Cost | Notes
1 | U1,U7 | R1S-1212 | GS_Library:5_pin_single_smd |  |  | 2 | 919-R1S-1212 | 945-3298-ND | 1 | $7.75 | 7 | $54.25
2 | U2 | LM317L_SOT-89 | Package_TO_SOT_SMD:SOT-89-3 | LM317LCPK |  | 1 | 595-LM317LCPK | 296-26093-1-ND | 10 | $0.44 | 10 | $4.37
3 | U6,U8 | Si8271DB-IS | Package_SO:SOIC-8_3.9x4.9mm_P1.27mm | Si8271DB-IS |  | 2 | 634-Si8271DB-IS | 336-3532-5-ND | 10 | $2.68 | 10 | $26.77
4 | Q1,Q2 | STP100N10F7 | Package_TO_SOT_THT:TO-220-3_Vertical | STP100N10F7 |  | 2 | 511-STP100N10F7 | 497-13550-5-ND | 1 | $0.27 | 7 | $1.88 | Schematic calls for STB100N10F7, this is D2PAK part. PCB has TO-220 parts.
5 | C5,C7,C8,C9,C25 | 100 nF, 16 V | Capacitor_SMD:C_0805_2012Metric | 885012207098 |  | 5 | 710-885012207098 | 732-8080-1-ND | 10 | $0.04 | 20 | $0.76
6 | C27,C36,C37 | 1 uF, 25V | Capacitor_SMD:C_0805_2012Metric | 885012207103 |  | 3 | 710-85012207103 | 732-7678-1-ND | 10 | $0.17 | 10 | $1.69
7 | C4, C6,C26,C34,C35 | 10 uF, 25V | Capacitor_SMD:C_0805_2012Metric | GRM21BR61H106KE43L |  | 5 |  | 490-18663-1-ND | 10 | $0.17 | 20 | $3.48
8 | C1,C12,C15,C16,C17,C18,C19,C20,C21,C22,C23,C24 | 10 uF, 50 V, X7R | Capacitor_SMD:C_1210_3225Metric | Wurth 885012209073 | CL32B106KBJNNNE | 12 | 710-885012209073 | 1276-3387-1-ND | 10 | $0.35 | 40 | $14.00
9 | C10,C11,C13,C14 | 1000 uF, 200 V | Capacitor_THT:CP_Radial_D30.0mm_P10.00mm_SnapIn | Wurth 861141085021 |  | 4 | 710-861141085021 | 732-11901-ND | 10 | $5.14 | 20 | $102.80
10 | R23,R29 | 2 ohm | Resistor_SMD:R_0805_2012Metric | CRCW08052R00FKEA |  | 2 | 71-RCW08052R00FKEA | 541-2.00CCCT-ND | 10 | $0.05 | 10 | $0.50
11 | R22,R24 | 87 ohm, 1% | Resistor_SMD:R_0805_2012Metric |  | ERJ-6ENF86R6V | 2 |  | P86.6CCT-ND | 10 | $0.05 | 10 | $0.52 | ls off
12 | R18,R19 | 100 ohm, 1% | Resistor_SMD:R_0805_2012Metric |  | ERJ-P06F1000V | 2 |  | P16057CT-ND | 10 | $0.08 | 10 | $0.84 | dead time
13 | R11 | 470 ohm | Resistor_SMD:R_0805_2012Metric | RC0805FR-07470RL |  | 1 | 603-RC0805FR-07470RL | 311-470CRCT-ND | 10 | $0.01 | 10 | $0.12
14 | R1,R2,R3,R4,R5,R6,R7,R8 | R820, 1%, 1206, 100ppm | Resistor_SMD:R_1206_3216Metric | RCWE1206R820FKEA |  | 8 | 71-RCWE1206R820FKEA | RCWE.82ECT-ND | 10 | $0.18 | 30 | $5.37
15 | (Alt for R1,R2,R3,R4,R5,R6,R7,R8) | R820, 1%, 1206, 200ppm | Resistor_SMD:R_1206_3216Metric | ERJ-8BQFR82V |  | 8 | 667-ERJ-8BQFR82V
16 | R12 | 1.43k ohm | Resistor_SMD:R_0805_2012Metric |  | CRCW08051K43FKEA | 1 |  | 541-1.43KCCT-ND | 10 | $0.04 | 10 | $0.41
17 | R9,R10 | 3k 0.5W | Resistor_THT:R_Axial_DIN0309_L9.0mm_D3.2mm_P15.24mm_Horizontal | RSF100JB-73-3K |  | 2 | 603-RSF100JB-73-3K | 3.0KW-1-ND | 10 | $0.12 | 10 | $1.19 | Part specs are larger than PCB footprint, but values are correct. Float part for heat dissipation?
18 | R13,R14,R20,R21 | 10k ohm, 1% | Resistor_SMD:R_0805_2012Metric |  | ERJ-6ENF1002V | 4 |  | P10.0KCCT-ND | 10 | $0.05 | 20 | $1.04 | hs off, enable pins
19 | R30,R31 | 100k ohm | Resistor_SMD:R_0805_2012Metric | RC0805FR-07100KL |  | 2 | 603-RC0805FR-07100KL | 311-100KCRCT-ND | 10 | $0.01 | 10 | $0.10
20 | F1,F2 | 6.3A FA | Fuse:Fuseholder_TR5_Littelfuse_No560_No460 | Littelfuse 37316300410 |  | 2 | 576-37316300410 | WK3066BK-ND | 10 | $1.27 | 10 | $12.70
21 | (Also for F1, F2) | Fuse holder |  | Littelfuse #560, 6.3A | 56000001319 | 2 | 576-56000001319 | WK0001-ND | 10 | $0.89 | 10 | $8.90
24 | J3,J4,J5,J6 | Arduino Headers |  | Adafruit 85 |  | 1 | 485-85 | 1528-1074-ND | 1 | $1.95 | 4 | $7.80
25 | J21,J22 | Conn_02x03_Top_Bottom | Connector_PinHeader_2.54mm:PinHeader_2x03_P2.54mm_Vertical | Samtec SSQ10301GD |  | 2 | 200-SSQ10301GD | SAM1179-03-ND | 1 | $1.25 | 7 | $8.79 | Schematic/layout specify pin header, but BOM part is socket. Photo shows sockets.
26 | J11,J12 | Conn_02x02_Top_Bottom | Connector_PinSocket_2.54mm:PinSocket_2x02_P2.54mm_Vertical | Samtec SSQ10203FD | SSQ-102-01-L-D | 2 | 200-SSQ10203FD | SAM11905-ND | 1 | $1.41 | 7 | $9.87 | Specified part is custom order. Replacement has 2.64 mm tail vs 10.00 mm
27 | J9 | Screw_Terminal_01x02 | TerminalBlock:TerminalBlock_bornier-2_P5.08mm | TB006-508-02BE |  | 1 | 490-TB006-508-02BE | 102-6191-ND | 10 | $0.39 | 10 | $3.89
28 | J15 | Banana Jack, Red | Library:Banana_4mm_pcb |  | 973582101 | 1 |  | 973582101-ND | 1 | $3.39 | 4 | $13.56 | Footprint calls for socket with 15 mm pitch. Standard parts are either 10 mm or 17 mm. Modify and glue to fit.
29 | J16 | Banana Jack, Blue | Library:Banana_4mm_pcb |  | 105-0760-001 | 1 |  | J115-ND | 1 | $1.46 | 4 | $5.84
30 | J17 | Banana Jack, Black | Library:Banana_4mm_pcb |  | 973582100 | 1 |  | 973582100-ND | 1 | $3.39 | 4 | $13.56
31 | J13,J19 | BNC | Connector_Coaxial:BNC_TEConnectivity_1478204_Vertical | TE 1478204 (obsolete) | Amp RF 112404 | 2 |  | ACX1051-ND | 10 | $2.94 | 10 | $29.40
32 | TP16,TP18 | Binding Post, Red | TestPoint:TestPoint_Plated_Hole_D5.0mm | BU-P3760-6 |  | 2 | 548-BU-P3760-6 | 314-1496-ND | 1 | $5.33 | 7 | $37.31
33 | TP17,TP19 | Binding Post, Black | TestPoint:TestPoint_Plated_Hole_D5.0mm | BU-P3760-0 |  | 2 | 548-BU-P3760-0 | 314-1492-ND | 1 | $6.06 | 7 | $42.42
34 | TP4,TP5,TP12 | Clip loop, YEL | TestPoint:TestPoint_Keystone_5010-5014_Multipurpose | Keystone 5004 |  | 3 | 534-5004 | 36-5004-ND | 10 | $0.26 | 10 | $2.56
35 | TP6,TP13,TP15 | Clip loop, ORG | TestPoint:TestPoint_Keystone_5010-5014_Multipurpose | Keystone 5003 |  | 3 | 534-5003 | 36-5003-ND | 10 | $0.26 | 10 | $2.56
36 | TP10,TP14 | Clip loop, WHITE | TestPoint:TestPoint_Keystone_5010-5014_Multipurpose | Keystone 5002 |  | 2 | 534-5002 | 36-5002-ND | 10 | $0.20 | 10 | $2.03
37 | TP11 | Clip loop, BLACK | TestPoint:TestPoint_Keystone_5010-5014_Multipurpose | Keystone 5001 |  | 1 | 534-5001 | 36-5001-ND | 10 | $0.20 | 10 | $2.02
 |  |  |  |  |  |  |  |  |  |  | Total Cost: | $423.30

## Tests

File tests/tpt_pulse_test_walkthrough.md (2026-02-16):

# TPT Pulse Train Test Walkthrough and Troubleshooting

**Date:** 2026-02-11
**Script:** `tests/test_tpt_pulse_train.py`

This guide explains how to use the pulse train test script and documents a critical fix for pulse train persistence.

## 1. Overview
The `test_tpt_pulse_train.py` script allows you to:
1. Define a sequence of pulses (periods in seconds)
2. Load them into the NUCLEO-H503RB MCU (running `TPT_SCPI_Server` firmware)
3. Execute the pulse train on the gate driver outputs (PB10/PB4)

## 2. Usage Workflow

1. **Connect Hardware**: Ensure Nucleo is connected via USB and flashed with correct firmware.
2. **Run Script**:
   ```bash
   python tests/test_tpt_pulse_train.py
   ```
3. **Define Pulses**: Select **Option [1]** to enter pulses manually (e.g., `10e-6`, `20e-6`, `done`).
4. **Load to MCU**: Confirm with `y`.
5. **Run**: Select **Option [3]** to fire the pulses.
6. **Reuse (New Feature)**: To run again with different settings or just re-load:
   - Select **Option [1]** again.
   - You will be asked: `Keep existing pulse train? [Y/n]`
   - Press **Enter** to keep your previous data.

## 3. Troubleshooting & Known Issues

### Issue: "Pulse Train Amnesia" (Fixed 2026-02-11)
**Symptoms:**
- Script would run successfully once.
- On the second run (without restarting script), usage of Option [1] would crash or error out.
- The script did not remember the previously entered pulse train.

**Root Cause:**
1. **Serial Buffer Corruption**: `run_pulses` (Option 3) sends a command but doesn't wait for a response. The MCU might send debug limits or other data. The *next* command (sent by `add_pulse` validation) would read this stale data instead of its expected response, causing a crash.
2. **Scope of Variable**: The `pulses` list was defined inside the loop, resetting on every iteration.

**Fix Implemented:**
- **Persistence**: `pulses` variable moved to outer scope to persist across loop iterations.
- **Buffer Flushing**: Added `board.flush_buffer()` in `ST.py` and called it after every run to clear stale data.
- **Optimized Driver**: Removed per-pulse SCPI validation queries in `ST.py` (`add_pulse`) to reduce traffic and potential for desynchronization.

## 4. Hardware Setup
- **PB10**: Positive Pulse (High-side)
- **PB4**: Negative Pulse (Low-side)
- **PA3/PA4**: USART3 (SCPI Control)

---
*If you encounter serial errors, ensure no other terminal (like TeraTerm or Screen) is holding the COM port.*

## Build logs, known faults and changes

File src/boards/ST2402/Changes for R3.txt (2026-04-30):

ST2402 rev 2 needed board fixes

1) 12v power trace between U1 & U7 is missing
2) U1 & U7 footprint is off for Vin+ - pin 2
3) ideally a little more space between U1 & U7 for hand soldering - is tight
4) J13, J19 footprint is off or holes too small
5) standoffs too close to ST micro board
6) swap standoff and diff probe connector locations so can access current loop on top
7)

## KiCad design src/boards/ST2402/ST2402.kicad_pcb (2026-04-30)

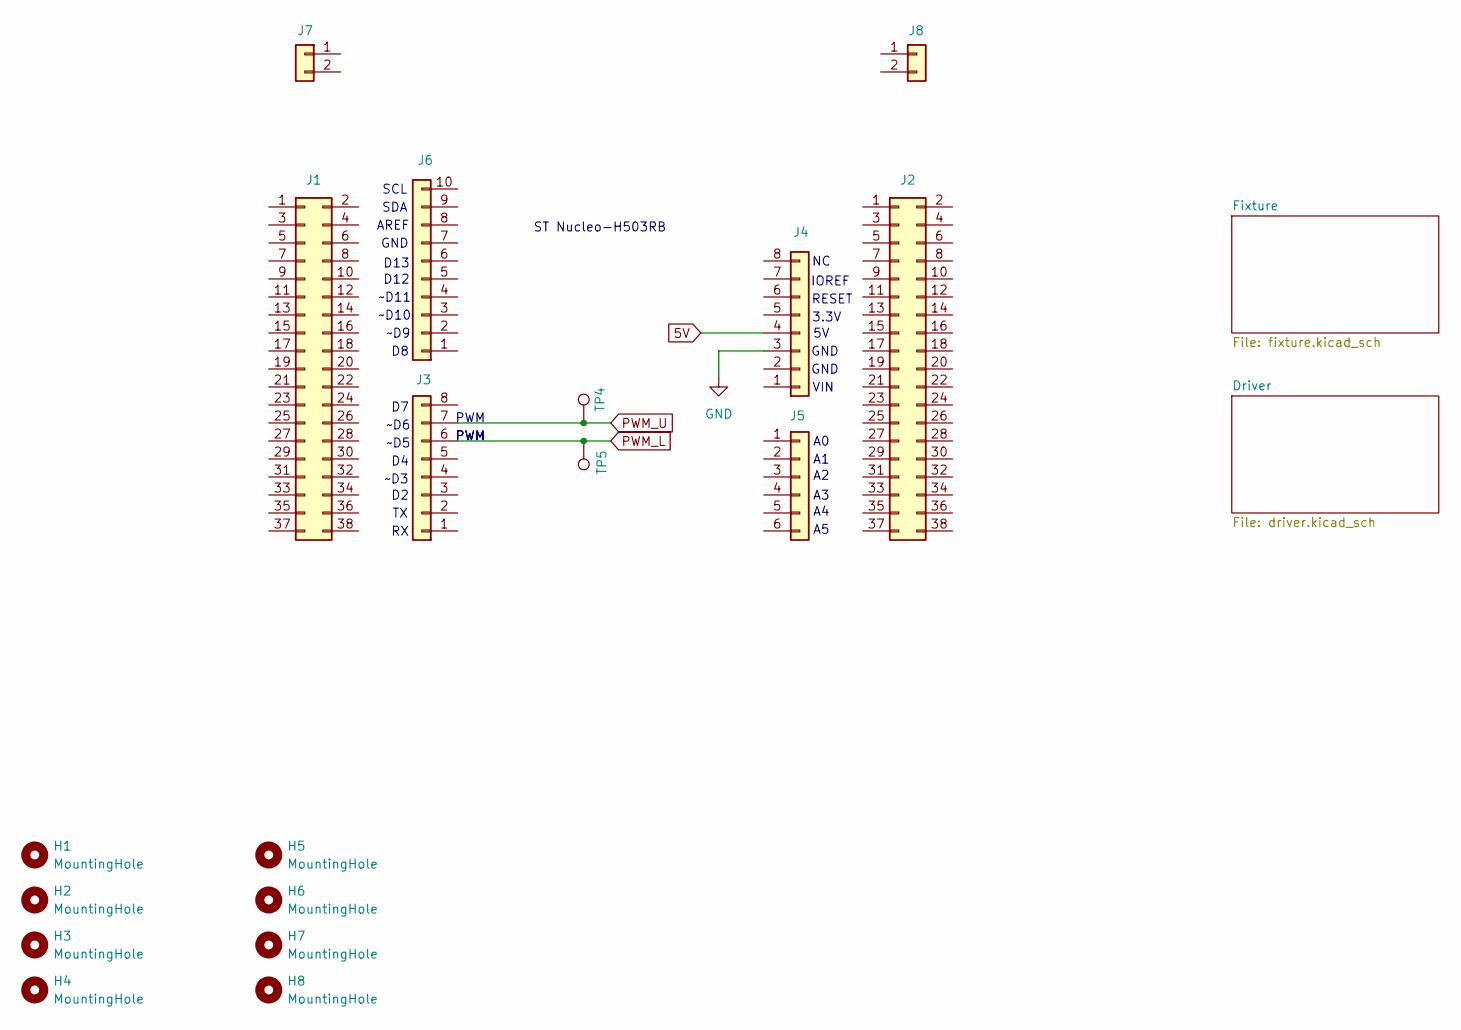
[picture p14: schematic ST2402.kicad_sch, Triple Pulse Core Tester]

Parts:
H1, H2, H3, H4, H5, H6, H7, H8: MountingHole; MountingHole_3.2mm_M3_DIN965
J1, J2: Conn_02x19_Odd_Even; PinHeader_2x19_P2.54mm_Vertical
J3, J4: Conn_01x08; PinHeader_1x08_P2.54mm_Vertical
J5: Conn_01x06; PinHeader_1x06_P2.54mm_Vertical
J6: Conn_01x10; PinHeader_1x10_P2.54mm_Vertical
J7, J8: Conn_01x02; PinHeader_1x02_P2.54mm_Vertical
TP4, TP5: TestPoint; TestPoint_Keystone_5010-5014_Multipurpose

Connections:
5V: J4.4
GND: J4.3; also elsewhere on the board
PWM_L: J3.6, TP5.1; also elsewhere on the board
PWM_U: J3.7, TP4.1; also elsewhere on the board

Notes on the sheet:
~D9
GND
3.3V
SCL
IOREF
SDA
D13
RESET
~D11
~D6
PWM
D12
~D5
~D3
AREF
VIN
~D10
ST Nucleo-H503RB

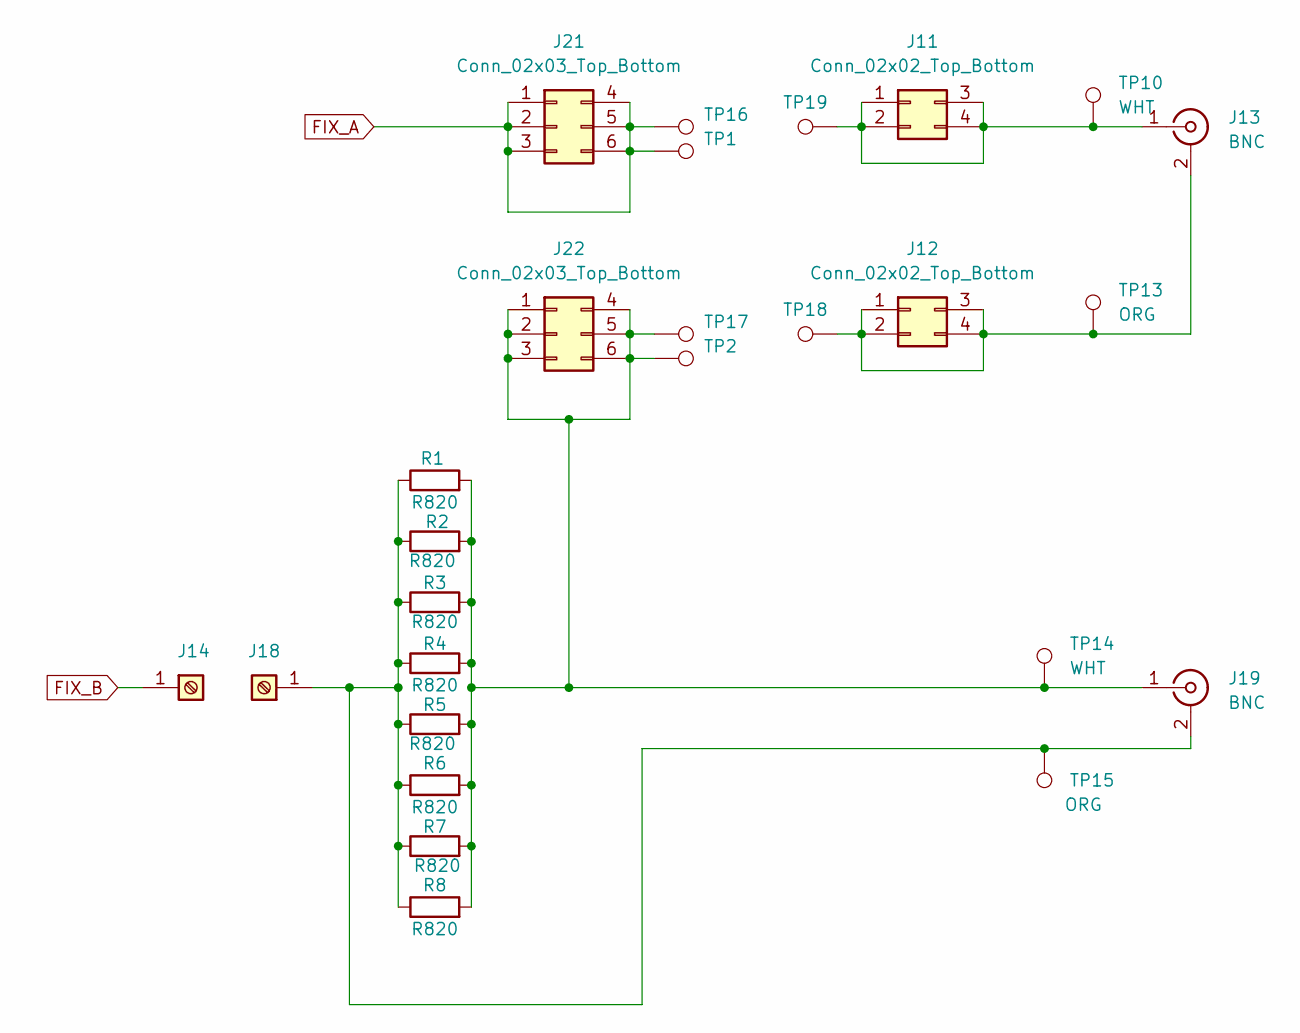
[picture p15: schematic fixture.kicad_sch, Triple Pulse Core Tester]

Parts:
J11, J12: Conn_02x02_Top_Bottom; PinSocket_2x02_P2.54mm_Vertical
J13, J19: BNC; BNC_TEConnectivity_1478204_Vertical
J14, J18: Screw_Terminal_01x01; TestPoint_Plated_Hole_D2.0mm
J21, J22: Conn_02x03_Top_Bottom; PinHeader_2x03_P2.54mm_Vertical
R1, R2, R3, R4, R5, R6, R7, R8: R820; R_1206_3216Metric
TP1, TP2, TP16, TP17, TP18, TP19: TestPoint; TestPoint_Plated_Hole_D5.0mm
TP10, TP14: WHT; TestPoint_Keystone_5010-5014_Multipurpose
TP13, TP15: ORG; TestPoint_Keystone_5010-5014_Multipurpose

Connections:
FIX_A: J21.1, J21.2, J21.3, J21.4, J21.5, J21.6, TP1.1, TP16.1; also elsewhere on the board
FIX_B: J14.1; also elsewhere on the board
unnamed: J11.1, J11.2, J11.3, J11.4, J13.1 (In), TP10.1, TP19.1
unnamed: J12.1, J12.2, J12.3, J12.4, J13.2 (Ext), TP13.1, TP18.1
unnamed: J18.1, J19.2 (Ext), R1.1, R2.1, R3.1, R4.1, R5.1, R6.1, R7.1, R8.1, TP15.1
unnamed: J19.1 (In), J22.1, J22.2, J22.3, J22.4, J22.5, J22.6, R1.2, R2.2, R3.2, R4.2, R5.2, R6.2, R7.2, R8.2, TP2.1, TP14.1, TP17.1

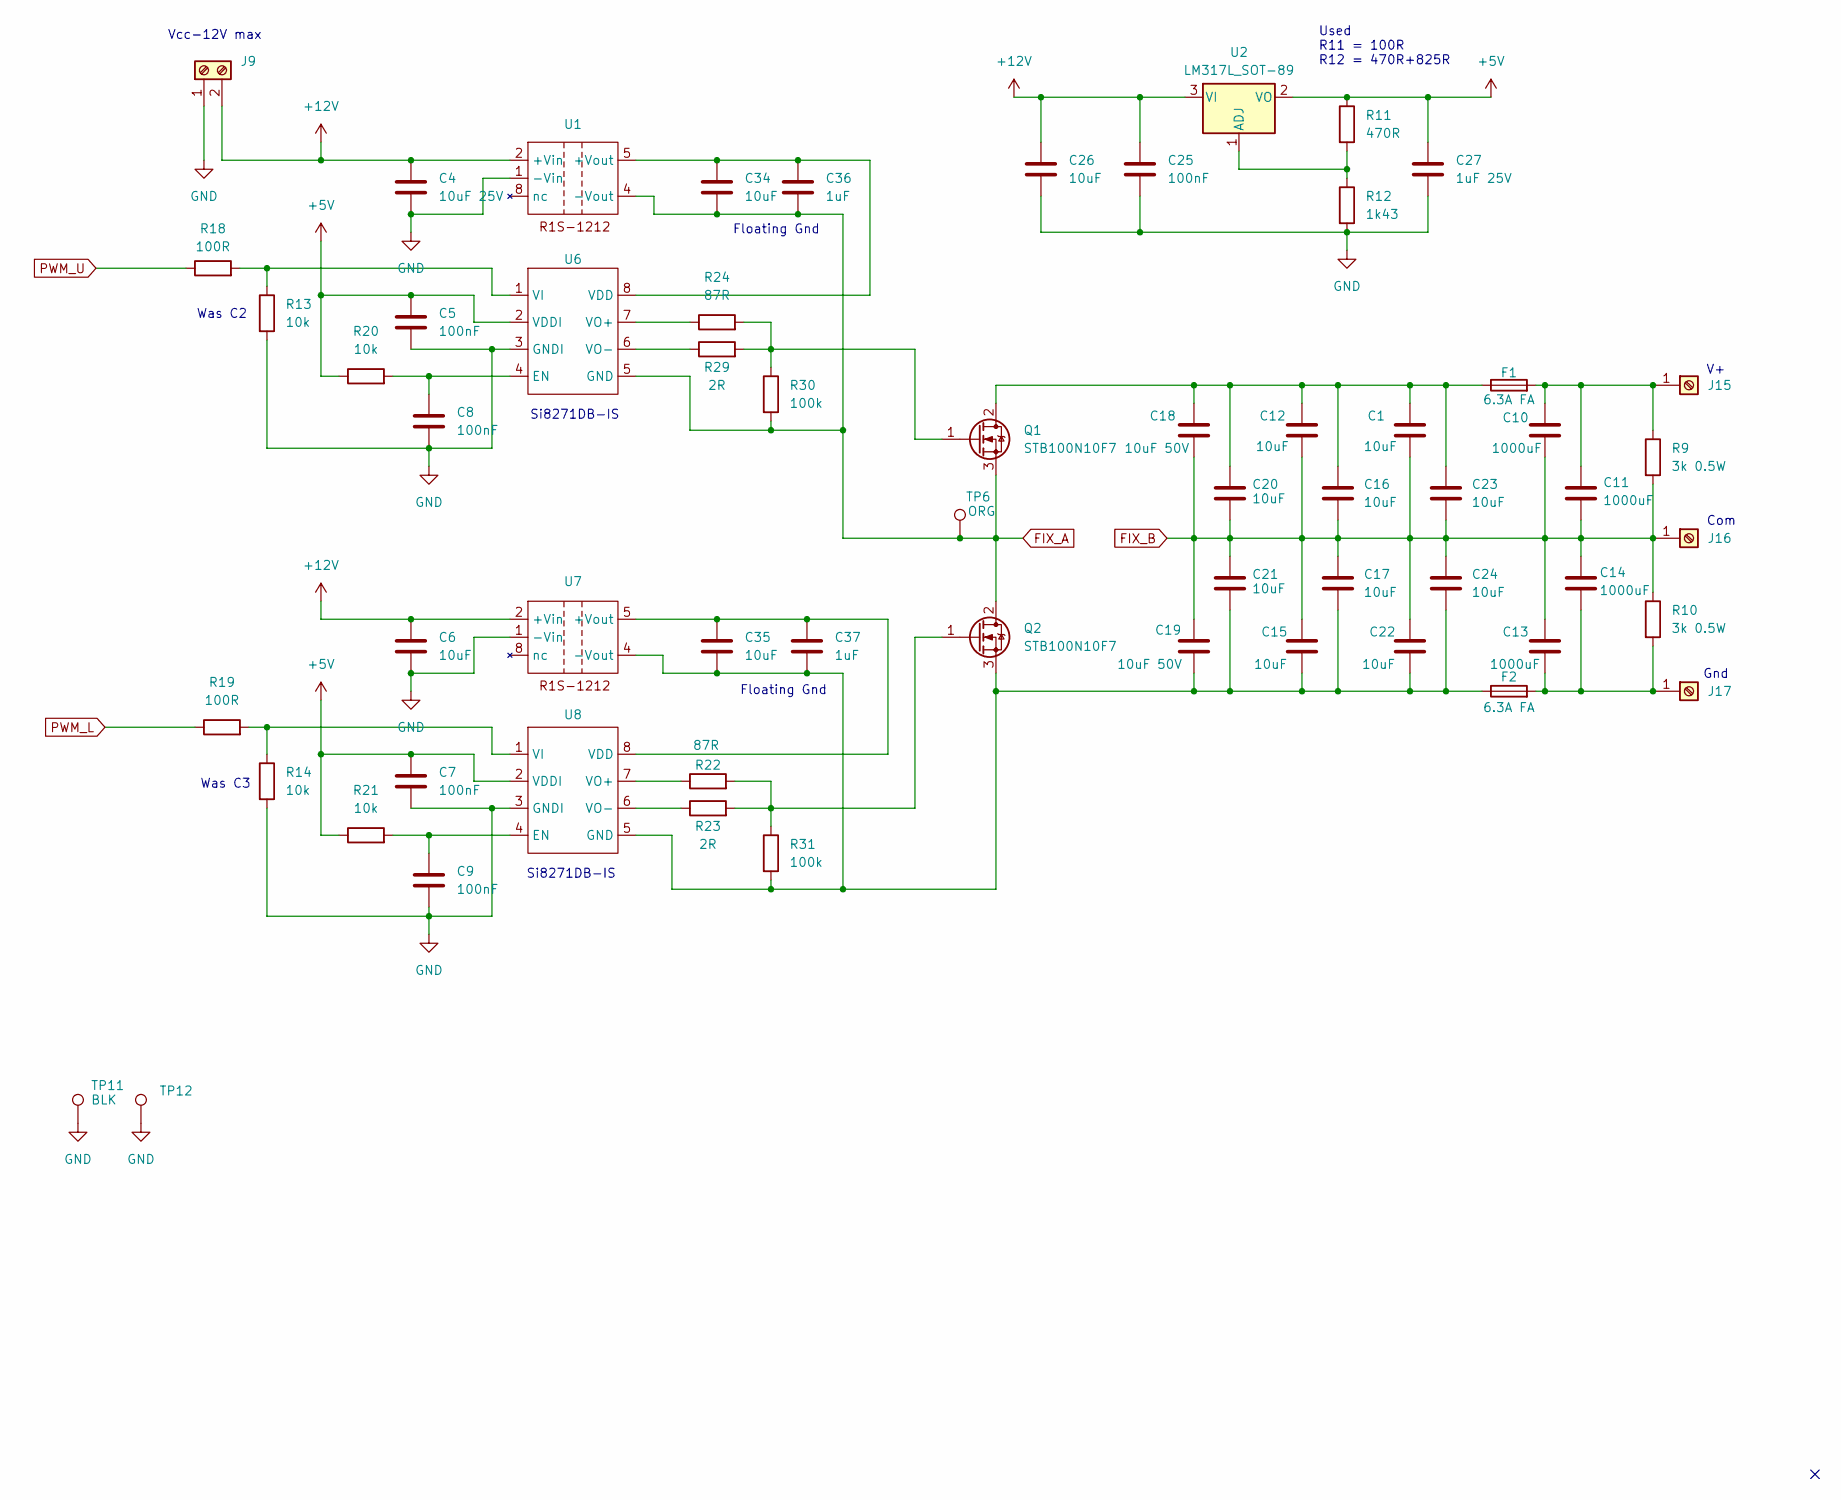
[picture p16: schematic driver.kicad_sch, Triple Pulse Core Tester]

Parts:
C1, C12, C15, C16, C17, C20, C21, C22, C23, C24: 10uF; C_1210_3225Metric
C4: 10uF 25V; C_0805_2012Metric
C5, C7, C8, C9, C25: 100nF; C_0805_2012Metric
C6, C26, C34, C35: 10uF; C_0805_2012Metric
C10, C11, C13, C14: 1000uF; CP_Radial_D30.0mm_P10.00mm_SnapIn
C18, C19: 10uF 50V; C_1210_3225Metric
C27: 1uF 25V; C_0805_2012Metric
C36, C37: 1uF; C_0805_2012Metric
F1, F2: 6.3A FA; Fuseholder_TR5_Littelfuse_No560_No460
J9: Screw_Terminal_01x02; TerminalBlock_bornier-2_P5.08mm
J15, J16, J17: Screw_Terminal_01x01; Banana_4mm_pcb
Q1, Q2: STB100N10F7; TO-220-3_Vertical
R9, R10: 3k 0.5W; R_Axial_DIN0309_L9.0mm_D3.2mm_P15.24mm_Horizontal
R11: 470R; R_0805_2012Metric
R12: 1k43; R_0805_2012Metric
R13, R14, R20, R21: 10k; R_0805_2012Metric
R18, R19: 100R; R_0805_2012Metric
R22, R24: 87R; R_0805_2012Metric
R23, R29: 2R; R_0805_2012Metric
R30, R31: 100k; R_0805_2012Metric
TP6: ORG; TestPoint_Keystone_5010-5014_Multipurpose
TP11: BLK; TestPoint_Keystone_5010-5014_Multipurpose
TP12: TestPoint; TestPoint_Keystone_5010-5014_Multipurpose
U1, U7: 5_pin_single_smd
U2: LM317L_SOT-89; SOT-89-3
U6, U8: SOIC-8_3.9x4.9mm_P1.27mm

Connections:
+5V: C5.1, C7.1, C27.1, R11.1, R20.1, R21.1, U2.2 (VO), U6.2 (VDDI), U8.2 (VDDI)
+12V: C4.1, C6.1, C25.1, C26.1, J9.2, U1.2 (+Vin), U2.3 (VI), U7.2 (+Vin)
FIX_A: C34.2, C36.2, Q1.3 (S), Q2.2 (D), R30.2, TP6.1, U1.4 (-Vout), U6.5 (GND); also elsewhere on the board
FIX_B: C1.2, C10.2, C11.2, C12.2, C13.1, C14.1, C15.1, C16.2, C17.1, C18.2, C19.1, C20.2, C21.1, C22.1, C23.2, C24.1, J16.1, R9.2, R10.1; also elsewhere on the board
GND: C4.2, C5.2, C6.2, C7.2, C8.2, C9.2, C25.2, C26.2, C27.2, J9.1, R12.2, R13.2, R14.2, TP11.1, TP12.1, U1.1 (-Vin), U6.3 (GNDI), U7.1 (-Vin), U8.3 (GNDI); also elsewhere on the board
unnamed: C10.1, C11.1, F1.2, J15.1, R9.1
unnamed: C13.2, C14.2, F2.2, J17.1, R10.2
unnamed: C1.1, C12.1, C16.1, C18.1, C20.1, C23.1, F1.1, Q1.2 (D)
unnamed: Q1.1 (G), R24.2, R29.2, R30.1
unnamed: Q2.1 (G), R22.2, R23.2, R31.1
unnamed: C15.2, C17.2, C19.2, C21.2, C22.2, C24.2, C35.2, C37.2, F2.1, Q2.3 (S), R31.2, U7.4 (-Vout), U8.5 (GND)
unnamed: C34.1, C36.1, U1.5 (+Vout), U6.8 (VDD)
unnamed: R11.2, R12.1, U2.1 (ADJ)
unnamed: C8.1, R20.2, U6.4 (EN)
unnamed 19: R13.1, R18.2, U6.1 (VI); also elsewhere on the board
unnamed: R24.1, U6.7 (VO+)
unnamed: R29.1, U6.6 (VO-)
unnamed: C35.1, C37.1, U7.5 (+Vout), U8.8 (VDD)
unnamed: C9.1, R21.2, U8.4 (EN)
unnamed 24: R14.1, R19.2, U8.1 (VI); also elsewhere on the board
unnamed: R22.1, U8.7 (VO+)
unnamed: R23.1, U8.6 (VO-)
PWM_L: R19.1; also elsewhere on the board
PWM_U: R18.1; also elsewhere on the board

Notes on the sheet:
Was C3
Si8271DB-IS
Was C2
Vcc-12V max
Floating Gnd
Used R11 = 100R R12 = 470R+825R
Gnd
Com

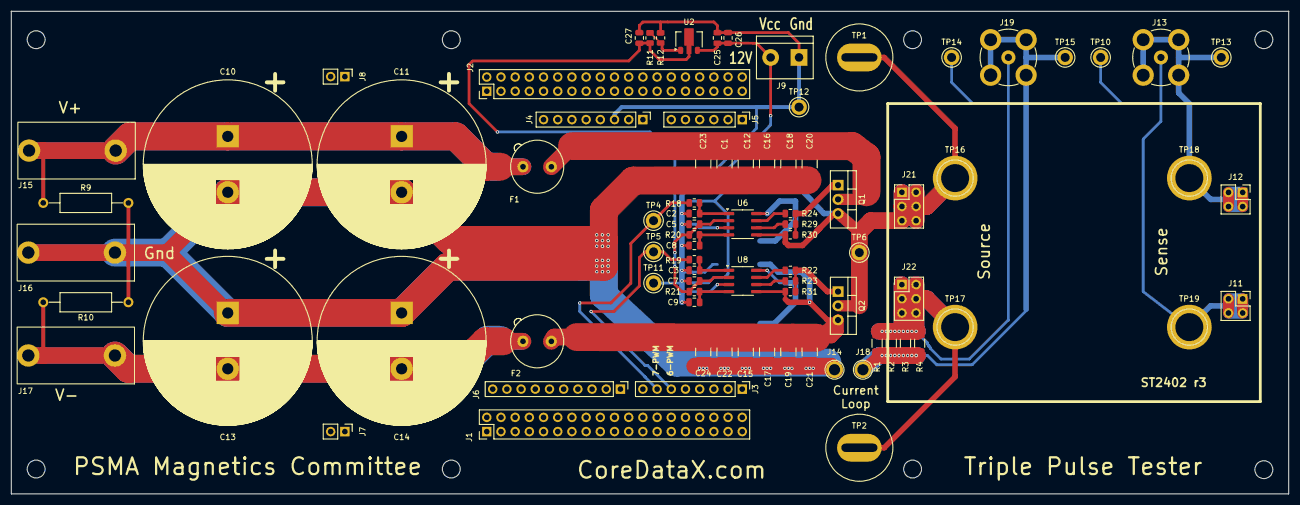
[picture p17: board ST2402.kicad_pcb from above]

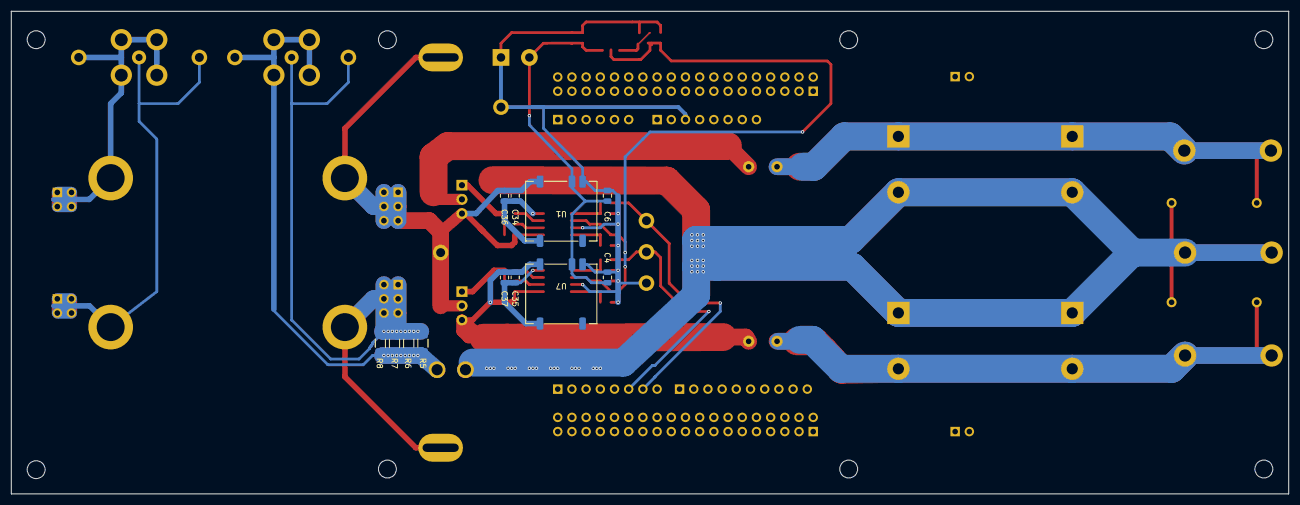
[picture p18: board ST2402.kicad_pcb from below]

Board: 2 copper layers, 228.6 x 86.4 mm, 105 parts (12 on the bottom side), 28 nets.

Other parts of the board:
C2, C3: 100nF; C_0805_2012Metric

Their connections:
GND: C2.2, C3.2; also elsewhere on the board
unnamed 19: C2.1; also elsewhere on the board
unnamed 24: C3.1; also elsewhere on the board

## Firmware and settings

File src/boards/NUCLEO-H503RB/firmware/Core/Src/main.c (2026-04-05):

/**
 * Bare-metal main for TPT SCPI Server (NUCLEO-H503RB).
 *
 * Peripherals initialised with direct register writes — no HAL / LL.
 *   - System clock: HSE 24 MHz → PLL1 → 250 MHz
 *   - USART3 on PA3 (RX) / PA4 (TX), 115 200 baud, RX interrupt
 *   - GPIO: PB10 (PositivePulse), PB4 (NegativePulse), PA5 (LED2), PC13 (Button)
 *   - EXTI13 rising edge for user button
 *   - SysTick 1 ms tick
 *   - ICACHE enabled
 */
#include "main.h"
#include "tpt-scpi.h"
#include <stdio.h>
#include <string.h>

/* ── Millisecond tick ── */
volatile uint32_t uwTick = 0;

/* ── UART double-buffer for single-byte reception ── */
#define RX_BUFFER_SIZE  1
static uint8_t aRXBufferA[RX_BUFFER_SIZE];
static uint8_t aRXBufferB[RX_BUFFER_SIZE];
static volatile uint32_t uwNbReceivedChars;
static volatile uint32_t uwBufferReadyIndication;
static uint8_t *pBufferReadyForUser;
static uint8_t *pBufferReadyForReception;

/* ── Forward declarations ── */
static void SystemClock_Config(void);
static void GPIO_Init(void);
static void USART3_Init(void);
static void ICACHE_Init(void);
static void StartReception(void);
static void HandleContinuousReception(void);

/* ════════════════════════════════════════════════════════════════════ */

int main(void)
{
    SystemClock_Config();
    GPIO_Init();
    USART3_Init();
    ICACHE_Init();

    /* SysTick: 1 ms tick at 250 MHz */
    SysTick_Config(250000000U / 1000U);

    /* LED off */
    GPIOA->BSRR = LED2_Pin << 16;

    /* Start UART reception */
    StartReception();

    /* Initialise SCPI */
    SCPI_Init(&scpi_context,
              scpi_commands,
              &scpi_interface,
              scpi_units_def,
              SCPI_IDN1, SCPI_IDN2, SCPI_IDN3, SCPI_IDN4,
              scpi_input_buffer, SCPI_INPUT_BUFFER_LENGTH,
              scpi_error_queue_data, SCPI_ERROR_QUEUE_SIZE);

    printf("TPT 2402 r2 bare-metal SCPI\r\n");

    reset_pins();

    while (1) {
        HandleContinuousReception();
    }
}

/* ── Clock: HSE 24 MHz → PLL1 → SYSCLK 250 MHz ── */
static void SystemClock_Config(void)
{
    /* Flash latency 5 WS for 250 MHz at VOS0 */
    FLASH->ACR = (FLASH->ACR & ~FLASH_ACR_LATENCY) | FLASH_ACR_LATENCY_5WS;
    while ((FLASH->ACR & FLASH_ACR_LATENCY) != FLASH_ACR_LATENCY_5WS) {}

    /* Voltage scaling VOS0 (highest performance) */
    PWR->VOSCR = (PWR->VOSCR & ~PWR_VOSCR_VOS) | (3U << PWR_VOSCR_VOS_Pos);
    while (!(PWR->VOSSR & PWR_VOSSR_VOSRDY)) {}

    /* Enable HSE (24 MHz crystal on NUCLEO-H503RB) */
    RCC->CR |= RCC_CR_HSEON;
    while (!(RCC->CR & RCC_CR_HSERDY)) {}

    /* Configure PLL1: HSE/12 × 250 / 2 = 250 MHz
     *   PLL input  = 24 / 12 = 2 MHz   (range 2–4 MHz)
     *   VCO output = 2 × 250 = 500 MHz  (wide range)
     *   P output   = 500 / 2 = 250 MHz                    */
    RCC->PLL1CFGR = (3U  << RCC_PLL1CFGR_PLL1SRC_Pos)   /* HSE */
                  | (12U << RCC_PLL1CFGR_PLL1M_Pos)      /* M = 12 */
                  | (1U  << RCC_PLL1CFGR_PLL1RGE_Pos)    /* Input 2–4 MHz */
                  | (0U  << RCC_PLL1CFGR_PLL1VCOSEL_Pos) /* Wide VCO */
                  | RCC_PLL1CFGR_PLL1PEN;                 /* Enable P output */

    /* N = 250 (register value N−1 = 249), P = 2 (P−1 = 1), Q = 2, R = 2 */
    RCC->PLL1DIVR = ((250U - 1U) << RCC_PLL1DIVR_PLL1N_Pos)
                  | ((2U - 1U)   << RCC_PLL1DIVR_PLL1P_Pos)
                  | ((2U - 1U)   << RCC_PLL1DIVR_PLL1Q_Pos)
                  | ((2U - 1U)   << RCC_PLL1DIVR_PLL1R_Pos);

    /* Enable PLL1 */
    RCC->CR |= RCC_CR_PLL1ON;
    while (!(RCC->CR & RCC_CR_PLL1RDY)) {}

    /* Switch SYSCLK to PLL1 */
    RCC->CFGR1 = (RCC->CFGR1 & ~RCC_CFGR1_SW) | (3U << RCC_CFGR1_SW_Pos);
    while ((RCC->CFGR1 & RCC_CFGR1_SWS) != (3U << RCC_CFGR1_SWS_Pos)) {}

    /* AHB / APB prescalers = 1 (default) */
    RCC->CFGR2 = 0;

    SystemCoreClock = 250000000U;
}

/* ── GPIO init ── */
static void GPIO_Init(void)
{
    /* Enable clocks for GPIOA, GPIOB, GPIOC */
    RCC->AHB2ENR |= RCC_AHB2ENR_GPIOAEN | RCC_AHB2ENR_GPIOBEN | RCC_AHB2ENR_GPIOCEN;
    /* Short delay for clock to stabilise */
    __DSB();

    /* ── PB10 (PositivePulse) + PB4 (NegativePulse): output, push-pull, very-high speed, pull-down ── */
    /* MODER: 01 = output */
    GPIOB->MODER &= ~((3U << (10*2)) | (3U << (4*2)));
    GPIOB->MODER |=  ((1U << (10*2)) | (1U << (4*2)));
    /* OTYPER: 0 = push-pull (default) */
    GPIOB->OTYPER &= ~(PositivePulse_Pin | NegativePulse_Pin);
    /* OSPEEDR: 11 = very high */
    GPIOB->OSPEEDR |= ((3U << (10*2)) | (3U << (4*2)));
    /* PUPDR: 10 = pull-down */
    GPIOB->PUPDR &= ~((3U << (10*2)) | (3U << (4*2)));
    GPIOB->PUPDR |=  ((2U << (10*2)) | (2U << (4*2)));
    /* Start LOW */
    GPIOB->BSRR = (PositivePulse_Pin | NegativePulse_Pin) << 16;

    /* ── PA5 (LED2): output, push-pull, low speed ── */
    GPIOA->MODER &= ~(3U << (5*2));
    GPIOA->MODER |=  (1U << (5*2));

    /* ── PA3 (USART3_RX AF13) + PA4 (USART3_TX AF13): alternate function, high speed, pull-up ── */
    GPIOA->MODER &= ~((3U << (3*2)) | (3U << (4*2)));
    GPIOA->MODER |=  ((2U << (3*2)) | (2U << (4*2)));   /* AF mode */
    GPIOA->OSPEEDR |= ((2U << (3*2)) | (2U << (4*2)));   /* high speed */
    GPIOA->PUPDR &= ~((3U << (3*2)) | (3U << (4*2)));
    GPIOA->PUPDR |=  ((1U << (3*2)) | (1U << (4*2)));    /* pull-up */
    GPIOA->OTYPER &= ~((1U << 3) | (1U << 4));           /* push-pull */
    /* AFR[0]: AF13 = 0x0D for PA3 (bits 15:12) and PA4 (bits 19:16) */
    GPIOA->AFR[0] &= ~((0xFU << (3*4)) | (0xFU << (4*4)));
    GPIOA->AFR[0] |=  ((0xDU << (3*4)) | (0xDU << (4*4)));

    /* ── PC13 (USER_BUTTON): input, pull-down ── */
    GPIOC->MODER &= ~(3U << (13*2));   /* input (00) */
    GPIOC->PUPDR &= ~(3U << (13*2));
    GPIOC->PUPDR |=  (2U << (13*2));   /* pull-down */

    /* ── EXTI13 rising edge on PC13 ── */
    EXTI->EXTICR[3] = (EXTI->EXTICR[3] & ~(0xFFU << 8)) | (0x02U << 8);  /* port C, line 13 */
    EXTI->RTSR1 |= (1U << 13);   /* rising trigger */
    EXTI->IMR1  |= (1U << 13);   /* unmask */
    NVIC_SetPriority(EXTI13_IRQn, 3);
    NVIC_EnableIRQ(EXTI13_IRQn);
}

/* ── USART3: 115200 8N1, RX interrupt ── */
static void USART3_Init(void)
{
    /* Enable USART3 clock (APB1) */
    RCC->APB1LENR |= RCC_APB1LENR_USART3EN;
    __DSB();

    /* Disable USART while configuring */
    USART3->CR1 = 0;
    USART3->CR2 = 0;   /* 1 stop bit, async mode */
    USART3->CR3 = 0;   /* no flow control */
    USART3->PRESC = 0; /* prescaler /1 */

    /* BRR = PCLK1 / baud = 250 000 000 / 115 200 ≈ 2170 */
    USART3->BRR = 2170U;

    /* Enable TX + RX + USART */
    USART3->CR1 = USART_CR1_TE | USART_CR1_RE | USART_CR1_UE;

    /* NVIC */
    NVIC_SetPriority(USART3_IRQn, 0);
    NVIC_EnableIRQ(USART3_IRQn);
}

/* ── ICACHE ── */
static void ICACHE_Init(void)
{
    ICACHE->CR |= ICACHE_CR_EN;
}

/* ── putchar for printf → USART3 ── */
int __io_putchar(int ch)
{
    while (!(USART3->ISR & USART_ISR_TC)) {}
    USART3->TDR = (uint8_t)ch;
    return ch;
}

/* ── UART reception helpers (same logic as original) ── */
static void StartReception(void)
{
    pBufferReadyForReception = aRXBufferA;
    pBufferReadyForUser      = aRXBufferB;
    uwNbReceivedChars = 0;
    uwBufferReadyIndication = 0;

    /* Clear overrun flag, enable RXNE + error interrupts */
    USART3->ICR = USART_ICR_ORECF;
    USART3->CR1 |= USART_CR1_RXNEIE_RXFNEIE;
    USART3->CR3 |= USART_CR3_EIE;
}

static void HandleContinuousReception(void)
{
    if (uwBufferReadyIndication != 0) {
        uwBufferReadyIndication = 0;
        SCPI_Input(&scpi_context, (const char *)pBufferReadyForUser,
                   strlen((const char *)pBufferReadyForUser));
        GPIOA->ODR ^= LED2_Pin;   /* toggle LED */
    }
}

/* ── Callbacks (called from ISR context) ── */
void UserButton_Callback(void)
{
    printf("Button pressed\n\r");
}

void USART_CharReception_Callback(void)
{
    uint8_t *ptemp;

    pBufferReadyForReception[uwNbReceivedChars++] =
        (uint8_t)(USART3->RDR & 0xFFU);

    if (uwNbReceivedChars >= RX_BUFFER_SIZE) {
        uwBufferReadyIndication = 1;
        ptemp = pBufferReadyForUser;
        pBufferReadyForUser = pBufferReadyForReception;
        pBufferReadyForReception = ptemp;
        uwNbReceivedChars = 0;
    }
}

void Error_Callback(void)
{
    uint32_t isr = USART3->ISR;
    if (isr & USART_ISR_NE) {
        USART3->ICR = USART_ICR_NECF;
    }
    /* Clear other error flags to avoid stuck IRQ */
    if (isr & USART_ISR_FE)  USART3->ICR = USART_ICR_FECF;
    if (isr & USART_ISR_ORE) USART3->ICR = USART_ICR_ORECF;
}

void Error_Handler(void)
{
    __disable_irq();
    while (1) {}
}

void LED_Blinking(uint32_t period)
{
    while (1) {
        GPIOA->ODR ^= LED2_Pin;
        /* Simple ms delay using SysTick uwTick */
        uint32_t start = uwTick;
        while ((uwTick - start) < period) {}
    }
}

#ifdef USE_FULL_ASSERT
void assert_failed(uint8_t *file, uint32_t line) { (void)file; (void)line; }
#endif

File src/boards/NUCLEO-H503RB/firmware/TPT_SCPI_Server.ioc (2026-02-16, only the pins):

Mcu.UserName=STM32H503RBTx
PA3.Signal=USART3_RX
PA4.Signal=USART3_TX
PA5.GPIO_Label=LED2
PA5.Signal=GPIO_Output
PB10.GPIO_Label=PWM7
PB10.Signal=GPIO_Output
PB4(NJTRST).GPIO_Label=PWM4
PB4(NJTRST).Signal=GPIO_Output
PB6.Signal=I2C2_SCL
PB7.Signal=I2C2_SDA
PC13.GPIO_Label=USER_BUTTON
PC13.Signal=GPXTI13
PH0-OSC_IN(PH0).Signal=RCC_OSC_IN
PH1-OSC_OUT(PH1).Signal=RCC_OSC_OUT

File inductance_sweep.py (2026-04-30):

"""Inductance vs flux excursion - saturation curve.

For each PSU voltage V, fires N_HALF symmetric pulses at fixed F and
measures inductance two ways:

  L_dV  = V_pri_avg * T_half / dI_pp   (peak-to-peak slope, robust)
  L_fit = V_pri_avg / fit_slope(I)      (least-squares on the ramp)

Then plots L vs measured B_peak (B_peak = V_pri_avg * T_half / (2 * N1 * Ae)).

Pattern:
  - PWM triggering (channel 2, rail-to-rail logic from MCU) - reliable at
    every voltage including very low V_pri.
  - Coarse-then-narrow scope auto-ranging on V_pri and I.
  - PSU current safety abort.
  - Auto-stop when L_dV drops below L_DROP_REJECT * baseline (saturation).

Outputs:
  - inductance_sweep_results.csv
  - inductance_sweep.png  (L vs B_peak, both estimates)
"""
import os, sys, time
sys.path.insert(0, 'src')

import numpy as np
import pandas as pd
import matplotlib
matplotlib.use('Agg')
import matplotlib.pyplot as plt

from tpt import CoreLossMeasurement, theoretical_inductance, CORE_DATABASE


# ---------- configuration ----------
CORE          = "T26"
MATERIAL      = "3C90"
N1            = 10
F             = 25e3              # low f -> high B per volt; reaches saturation
N_HALF        = 8
SAMPLES       = 2500
CH_PWM        = 2
V_LIST        = [0.3, 0.5, 0.7, 1.0, 1.5, 2.0, 3.0, 5.0, 7.0, 9.0, 11.0]
# Safety guards — saturation produces high inductor current and PSU draw,
# heats the windings/MOSFETs. Multiple aborts triggered well before damage.
I_PSU_LIMIT   = 0.20    # PSU per-channel current trip (was 0.30; tightened)
DI_PP_LIMIT   = 0.50    # hard cap on inductor di_pp during burst [A]
L_DROP_REJECT = 0.6     # stop when L drops to 60% of baseline (catches knee earlier)
PSU_CURRENT_LIMIT_SETTING = 0.5  # set BK current trip on each rail [A]
COOLDOWN_S    = 1.0     # between cells, let the core dissipate

V_RANGES = [0.05, 0.1, 0.2, 0.5, 1.0, 2.0, 5.0, 10.0, 20.0]
I_RANGES = [0.02, 0.05, 0.1, 0.2, 0.5, 1.0, 2.0]


def find_pwm_edges(pwm, vthresh=1.0):
    above = pwm > vthresh
    rising  = np.where((~above[:-1]) &  above[1:])[0] + 1
    falling = np.where( above[:-1] & (~above[1:]))[0] + 1
    return rising, falling


def apply_labels(meas):
    s = meas.scope
    s.set_channel_label(meas.CH_VOLTAGE,   'V_pri')
    s.set_channel_label(meas.CH_SECONDARY, 'V_sec')
    s.set_channel_label(CH_PWM,            'PWM')
    s.set_channel_label(meas.CH_CURRENT,   'I')


def fire_and_capture(meas, pulses_s):
    s = meas.scope
    apply_labels(meas)
    meas.board.clear_pulses()
    for T in pulses_s:
        meas.board.add_pulse(T)
    s.set_rising_trigger(CH_PWM, 0.5, timeout=0)
    s.start_single_acquisition()
    time.sleep(0.4)
    meas.board.run_pulses(1)
    deadline = time.monotonic() + 5
    while True:
        if s.get_acquisition_state() == 'COMP': break
        if time.monotonic() > deadline:
            return None
        time.sleep(0.05)
    return s.read_data([meas.CH_VOLTAGE, meas.CH_SECONDARY, CH_PWM, meas.CH_CURRENT])


def psu_currents(psu):
    try:
        return psu.get_measured_current(1), psu.get_measured_current(2)
    except Exception:
        return float('nan'), float('nan')


def pick_smallest_range(peak_real, candidates, probe_scale, headroom=1.4):
    needed = peak_real * headroom
    for r in candidates:
        if r * probe_scale >= needed:
            return r
    return candidates[-1]


def configure_ranges(meas, rv, rsv, ri):
    s = meas.scope
    s.set_channel_configuration(meas.CH_VOLTAGE,   rv,  'DC', 0.0)
    s.set_channel_configuration(meas.CH_SECONDARY, rsv, 'DC', 0.0)
    s.set_channel_configuration(CH_PWM,            5.0, 'DC', 0.0)
    s.set_channel_configuration(meas.CH_CURRENT,   ri,  'DC', 0.0)
    apply_labels(meas)


def probe_at_voltage(meas, V, pulses_s, sample_dt):
    """Coarse capture, narrow ranges, re-capture. Returns (df_narrow, peaks, psu_I)."""
    meas.psu.set_source_voltage(meas.PSU_CHANNEL,     V)
    meas.psu.set_source_voltage(meas.PSU_CHANNEL_NEG, V)
    time.sleep(0.25)
    s = meas.scope
    s.set_sampling_time(sample_dt)
    configure_ranges(meas, V_RANGES[-1], V_RANGES[-1], I_RANGES[-1])
    df = fire_and_capture(meas, pulses_s)
    if df is None:
        return None, None, None
    vp_peak = float(np.abs(df['V_pri']).max())
    vs_peak = float(np.abs(df['V_sec']).max())
    i_peak  = float(np.abs(df['I']).max())
    rv  = pick_smallest_range(vp_peak, V_RANGES, meas.input_voltage_probe_scale)
    rsv = pick_smallest_range(vs_peak, V_RANGES, meas.output_voltage_probe_scale)
    ri  = pick_smallest_range(i_peak,  I_RANGES, meas.current_probe_scale)
    configure_ranges(meas, rv, rsv, ri)
    df2 = fire_and_capture(meas, pulses_s)
    if df2 is None:
        return None, None, None
    Ich1, Ich2 = psu_currents(meas.psu)
    peaks = dict(vp=vp_peak, vs=vs_peak, i=i_peak, rv=rv, rsv=rsv, ri=ri)
    return df2, peaks, (Ich1, Ich2)


def get_target_cycle(df):
    pwm = df['PWM'].to_numpy()
    rising, falling = find_pwm_edges(pwm)
    if len(rising) < 2: return None, None, None
    i_start = int(rising[-2])
    falls_after = falling[falling > i_start]
    if not len(falls_after): return None, None, None
    i_mid = int(falls_after[0])
    rises_after = rising[rising > i_mid]
    i_end = int(rises_after[0]) if len(rises_after) else len(pwm) - 1
    return i_start, i_mid, i_end
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

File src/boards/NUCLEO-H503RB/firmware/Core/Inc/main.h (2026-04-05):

/**
 * Bare-metal main header for TPT SCPI Server (NUCLEO-H503RB).
 * No HAL / LL dependencies — CMSIS register definitions only.
 */
#ifndef __MAIN_H
#define __MAIN_H

#ifdef __cplusplus
extern "C" {
#endif

#include "stm32h5xx.h"
#include <stdbool.h>
#include <stdint.h>

/* ── Pin definitions (bit masks for GPIOB->BSRR / GPIOA->BSRR) ── */
#define PositivePulse_Pin    (1U << 10)   /* PB10 */
#define NegativePulse_Pin    (1U << 4)    /* PB4  */
#define LED2_Pin             (1U << 5)    /* PA5  */
#define USER_BUTTON_Pin      (1U << 13)   /* PC13 */

/* ── LED blink periods (ms) ── */
#define LED_BLINK_FAST   200
#define LED_BLINK_SLOW   500
#define LED_BLINK_ERROR  1000

/* ── Millisecond tick (replaces HAL_GetTick / HAL_IncTick) ── */
extern volatile uint32_t uwTick;

/* ── Exported functions ── */
void Error_Handler(void);
void UserButton_Callback(void);
void USART_CharReception_Callback(void);
void Error_Callback(void);

#ifdef __cplusplus
}
#endif

#endif /* __MAIN_H */

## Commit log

2025-02-24 Added some SCPI commands to TPT board
2025-02-25 Added commands for running trains of pulses in the board
2025-02-25 Add files via upload
    ST2402 r1 files
    [ST2402.kicad_pcb, ST2402.kicad_sch, currentsense.kicad_sch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]
2025-02-25 Renamed board to ST2402
    [ST2402 BOM.xlsx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]
2025-03-03 Dummy power suppy added. Method for calculating core losses added
2025-03-06 Some fixes for Pico6000
    [PicoScope.py]
2025-03-07 Fixed voltage loop
2025-03-07 Fixed aDC count in Pico6000
    [PicoScope.py]
2025-03-13 Added probe scaling
2025-03-27 Separated voltages into positive and negative, and added adjustment for both separately
2025-03-27 Disabled power supply after test ends
2025-11-11 Update expected release time to Spring 2026
2026-01-20 Revert "Update expected release time to Spring 2026"
    This reverts commit 2349e430e09afb3095664301f5ecd4f1a9f3f0cf.
2026-01-20 Revert "Added untested PMBus integration"
    This reverts commit 0f5cf9eb41e18a78c24ba299d12d52899623f2a6.
    [main.c, tpt-scpi.c]
2026-02-16 Added the open-loop pulsetrain function with documentation. Corrected the two PWM pins to pull-down
    [ST.py, TPT_SCPI_Server.ioc, main.c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]
2026-02-16 Updated pcb files
    Added r2 and r3 gerbers and updated KiCad file (r3)
    [ST2402-B_Cu.gbr, ST2402-B_Mask.gbr, ST2402-B_Silkscreen.gbr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]
2026-02-17 Updated tpt-scpi.c to force two PWM pins LOW after a TPT run.
2026-02-24 Revert "Updated tpt-scpi.c to force two PWM pins LOW after a TPT run."
    This reverts commit 9ae1180b8c690a1077719c36808f065f06aa5e84.
    [tpt-scpi.c]
2026-02-24 LOW reset for both pulse outputs in tpt-scpi.c by fixing reset_pins() to drive PB10 and PB4 low (reset bits in BSRR), instead of leaving one pin high.
    Implemented
    Added a deterministic LOW reset for both pulse outputs in tpt-scpi.c by fixing reset_pins() to drive PB10 and PB4 low (reset bits in BSRR), instead of leaving one pin high.
    Updated TPT_RunPulses so outputs are forced LOW before a run starts, before each train repetition, after each train repetition, and once again at run completion.
    Updated SCPI_Reset to also force outputs LOW and clear running state, so reset always returns the board to a safe idle state.
    Why this solves it
    The previous end-of-run state could hold whichever comp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
    [tpt-scpi.c]
2026-03-05 Added R&S scope, GWinstek power supply, inductance to tpt and bascially all new tpt
2026-03-25 Adding Revison 3 Bill of materials
    Merged previous revision BoM with exported BoM from Revision 3 KiCAD project.
    [OpenTPT, Revision 3, Bill of Materials.xlsx]
2026-04-28 Fix multiple definition of uwTick linker error
    Use extern declaration in main.c since uwTick is already defined in the HAL library (stm32h5xx_hal.c).
    [main.c]
2026-04-28 Commit working APEC-demo state of TPT
    Lands the actual APEC-demo working tree on the APEC branch:
    - tpt.py: T18 core in CORE_DATABASE, close() helper for releasing
    hardware between measurements, current-scale tweak in
    InductanceMeasurement, set_probe_units guarded behind hasattr
    - PicoScope.py: accept "DC"/"AC" string coupling via _normalize_coupling
    - BK.py / GWINSTEK.py: APEC-time driver fixes
    - Firmware (tpt-scpi.c): the deadtime-helper version actually used at
    APEC (set_complementary_outputs_with_deadtime, fixed 500 ns deadtime,
    500 ns minimum period). Companion firmware files (main.c, main.h,
    tpt-scpi.h, stm32h5xx_it.c, system_stm32h5xx.c, FLASH.ld) rolled back
    to RS-scope t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
    [BK.py, GWINSTEK.py, PicoScope.py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]
2026-04-28 Fix tests for updated hardware: BK9129B PSU, PicoScope2408B, NUCLEO-H503RB firmware v0.1.0
    [BK.py]
2026-04-28 Fix diagnostic script scope timeout detection logic
    [diagnostic_core_loss.py]
2026-04-30 Add TPT (f, B) sweep with two-phase volt-second balancer
    New `tpt_sweep.py` runs the Triple Pulse Test over a (frequency, B_peak)
    grid and writes results + plots. The headline addition is the balancer:
    Phase A — V_pos held; iterate V_neg by -residual_vs / T_half_neg until
    the cycle's volt-second integral (∫V_sec·dt) is at the
    measurement noise floor (~0.15 µVs). Revert-to-best
    safeguards against single-burst noise overshoot.
    Phase B — scale BOTH rails by B_target/B_peak. Same scale on both sides
    preserves the V_pos/V_neg ratio achieved in A, so the volt-
    second balance survives.
    Outer A→B retry once if Phase B clipp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
    [investigate.py, main.c, main.h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]
2026-04-30 Add inductance sweep with saturation-knee safety guards
    `inductance_sweep.py` characterises L vs B by sweeping PSU voltage at
    fixed frequency. For each cell:
    L_dV = V_pri_avg * T_half / dI_pp (peak-to-peak slope, robust
    once dI_pp >> ADC LSB)
    L_fit = V_pri_avg / OLS_slope(I) (least-squares on the middle
    60% of the positive ramp,
    accurate at low signal)
    B_peak is computed from V_pri_avg (clean: no V_sec calibration needed).
    Why a new script instead of using src/tpt.py InductanceMeasurement:
    - That class triggers on the current cha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
    [inductance_sweep.py]
2026-09-01 Added Mouser part numbers
    Updated BOM and schematic with Mouser part numbers
    [ST2402 r5 BOM.xlsx, ST2402.kicad_sch, driver.kicad_sch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]

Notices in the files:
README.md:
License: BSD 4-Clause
